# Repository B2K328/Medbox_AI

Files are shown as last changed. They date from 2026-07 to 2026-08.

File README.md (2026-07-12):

# 🩺 MedBox AI  
### *Un boîtier médical intelligent et autonome utilisant l’Edge AI*  

  
  


---

## 📌 Présentation

**MedBox AI** est un projet de fin d’année (Licence 2 Informatique) visant à concevoir un **boîtier médical autonome** capable de réaliser un **diagnostic local en temps réel** à partir de constantes physiologiques.  

Le système embarque un modèle de classification exécuté directement sur un **ESP32** via **TensorFlow Lite Micro (TFLM)**, sans dépendance au cloud.

---

## 🎯 Objectifs du projet

- Concevoir une chaîne complète de **mesure → traitement → inférence → affichage** sur microcontrôleur.
- Exploiter l’**Edge AI** pour un diagnostic ultra-rapide et local.
- Garantir une architecture compatible avec les contraintes mémoire/CPU d’un ESP32.
- Démontrer la faisabilité d’un système médical intelligent à faible coût matériel.

---

## 🧠 Architecture embarquée (ESP32)

L’environnement d’exécution est fortement contraint :

| Élément | Spécification |
|---|---|
| Microcontrôleur | ESP32 |
| CPU | Xtensa double-cœur @ 240 MHz |
| Flash | 4 Mo |
| SRAM | 320 Ko |
| Cadre IA | TensorFlow Lite Micro (TFLM) |
| Allocation Tensor Arena | **8 Ko** (SRAM) |

---

## 🧩 Composants matériels

| Composant | Rôle |
|---|---|
| ESP32 | Unité centrale de contrôle et d’inférence |
| MAX30102 | Mesure du rythme cardiaque (BPM) et de la SpO2 |
| MLX90614 (IR) | Mesure de la température corporelle sans contact |
| Lecteur NFC | Lecture de l’âge patient depuis badge NFC |
| Écran OLED | Affichage des constantes et du diagnostic |

---

## 🔄 Flux logique du système (Machine à États)

Le firmware suit une séquence déterministe en **6 étapes** :

1. **Initialisation**
   - Bus I2C
   - Écran OLED
   - Capteurs
   - Moteur TensorFlow Lite Micro

2. **Attente NFC**
   - Scrutation active d’un badge
   - Lecture de l’**âge patient**

3. **Acquisition biométrique**
   - **MAX30102** : BPM + SpO2  
   - **MLX90614** : Température corporelle

4. **Prétraitement / Normalisation**
   - Transformation Z-Score des 4 variables :  
     **Âge, BPM, SpO2, Température**
   - Paramètres issus du scaler d’entraînement : `scaler_medbox.pkl`

5. **Inférence TinyML locale**
   - Injection du vecteur normalisé dans le tenseur d’entrée
   - Exécution du modèle TFLM sur ESP32
   - Récupération de l’index de pathologie (classification OMS)

6. **Restitution**
   - Affichage instantané des constantes + diagnostic sur OLED
   - Réinitialisation du cycle

---

## 🧮 Normalisation mathématique (Z-Score)

Avant inférence, chaque variable \(x\) est normalisée par :

\[
x_{\text{scaled}} = \frac{x - \mu}{\sigma}
\]

où :
- \(\mu\) = moyenne issue du dataset d’entraînement  
- \(\sigma\) = écart-type issu du dataset d’entraînement  

Cette étape garantit la cohérence entre les données capteurs en production et le domaine statistique appris par le modèle.

---

## ⚡ Performances mesurées (tests réels)

| Indicateur | Résultat |
|---|---|
| Accuracy du modèle (Python) | **95,63 %** |
| Temps d’inférence ESP32 | **126 à 136 µs** |
| Utilisation Flash | **27 %** |
| Variables globales | **9 %** |
| Tensor Arena SRAM | **8 Ko** |

### 🧪 Cas clinique simulé validé
Pour un patient simulé en **tachycardie + hypoxie sévère** :  
- 125 BPM  
- 85 % SpO2  
- 39.5 °C  

➡️ Le modèle embarqué détecte immédiatement **l’ID Pathologie OMS : 17** en **126 µs**.

---

## 🔒 Sécurité & confidentialité des données médicales

> [!IMPORTANT]  
> **MedBox AI fonctionne en Edge AI local** : l’inférence est réalisée directement sur l’ESP32, sans cloud.

> [!NOTE]  
> Cette architecture réduit l’exposition des données sensibles (constantes vitales), limite les dépendances réseau et améliore la résilience du système.

> [!WARNING]  
> Ce prototype est un **dispositif académique** et ne remplace pas un diagnostic médical professionnel.  
> Toute utilisation clinique réelle nécessite validation réglementaire, protocoles médicaux et conformité légale.

---

## 📁 Structure de projet recommandée

```text
Medbox_AI/
├─ src/                 # Code embarqué ESP32 (machine à états, capteurs, inférence)
│  ├─ main.ino
│  ├─ sensors/
│  ├─ nfc/
│  ├─ display/
│  └─ inference/
├─ model/               # Artefacts IA (modèle TFLite, paramètres de scaling)
│  ├─ medbox_model.tflite
│  ├─ model_data.h
│  └─ scaler_medbox.pkl
├─ docs/                # Documentation technique, schémas, rapport
│  ├─ architecture.md
│  ├─ bench_results.md
│  └─ images/
├─ data/                # Jeux de données / exports de test (si applicable)
├─ scripts/             # Scripts d’entraînement / conversion (Python)
└─ README.md
```

---

## 🛠️ Dépendances logicielles

À installer dans l’IDE Arduino (ou PlatformIO selon votre workflow) :

- **TensorFlowLite_ESP32** (TensorFlow Lite Micro pour ESP32)
- **Adafruit MLX90614 Library**
- **Librairie MAX30102** compatible ESP32
- **Librairie NFC** correspondant au module utilisé
- **Librairie écran OLED** (ex. SSD1306 selon le matériel)

---

## 🚀 Guide de démarrage rapide

### 1) Préparer l’environnement
1. Installer **Arduino IDE** (ou PlatformIO).
2. Ajouter la carte **ESP32** via le Boards Manager.
3. Installer les bibliothèques listées ci-dessus.

### 2) Préparer le projet
1. Cloner le dépôt :
   ```bash
   git clone https://github.com/B2K328/Medbox_AI.git
   cd Medbox_AI
   ```
2. Vérifier la présence :
   - du modèle embarqué (`.tflite` ou `model_data.h`)
   - des constantes de normalisation (issues de `scaler_medbox.pkl`)

### 3) Compiler & téléverser
1. Ouvrir `src/main.ino`.
2. Sélectionner la carte ESP32 et le port série.
3. Compiler puis téléverser.
4. Ouvrir le moniteur série pour observer :
   - l’acquisition capteur
   - les valeurs normalisées
   - le résultat d’inférence

---

## 🧪 Validation fonctionnelle

Checklist de validation recommandée :

- [ ] Initialisation I2C / capteurs / écran réussie  
- [ ] Lecture NFC de l’âge valide  
- [ ] Acquisition BPM / SpO2 / Température cohérente  
- [ ] Normalisation Z-Score conforme aux constantes d’entraînement  
- [ ] Inférence < 200 µs stable  
- [ ] Affichage OLED correct (constantes + ID OMS)

---

## 📚 Périmètre académique

Ce projet illustre une démarche d’ingénierie embarquée complète :

- conception d’une **pipeline TinyML** de bout en bout,
- adaptation aux contraintes d’un **microcontrôleur basse ressource**,
- intégration **capteurs + IA + IHM embarquée**.

---

## 👨‍💻 Auteur

**B2K328**  
Projet de fin d’année — **Licence 2 Informatique**  
Repository : [github.com/B2K328/Medbox_AI](https://github.com/B2K328/Medbox_AI)

---

## 📄 Licence

À préciser selon votre choix (`MIT`, `Apache-2.0`, ou licence académique spécifique).

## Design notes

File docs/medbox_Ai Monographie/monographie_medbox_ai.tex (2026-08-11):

\documentclass[12pt,a4paper]{report}

% ===================== PACKAGES =====================
\usepackage[utf8]{inputenc}
\usepackage[T1]{fontenc}
\usepackage[french]{babel}
\usepackage{lmodern}
\usepackage{geometry}
\geometry{a4paper, left=2.5cm, right=2.5cm, top=2.5cm, bottom=2.5cm}
\usepackage{graphicx}
\usepackage{float}
\usepackage{amsmath, amssymb}
\usepackage{listings}
\usepackage{xcolor}
\usepackage{booktabs}
\usepackage{hyperref}
\hypersetup{
    colorlinks=true,
    linkcolor=black,
    citecolor=black,
    urlcolor=blue,
    pdftitle={Monographie - MedBox AI},
}
\usepackage{fancyhdr}
\usepackage{titlesec}
\usepackage{setspace}
\onehalfspacing

% ===================== CONFIG CODE (LISTINGS) =====================
\lstset{
    basicstyle=\ttfamily\small,
    breaklines=true,
    frame=single,
    backgroundcolor=\color{gray!10},
    numbers=left,
    numberstyle=\tiny,
    keywordstyle=\color{blue},
    commentstyle=\color{gray},
}

% ===================== EN-TETES =====================
\setlength{\headheight}{14pt}
\pagestyle{fancy}
\fancyhf{}
\fancyhead[L]{\leftmark}
\fancyfoot[C]{\thepage}
\renewcommand{\headrulewidth}{0.4pt}

% ===================== INFOS A COMPLETER =====================
\newcommand{\titreProjet}{MedBox AI}
\newcommand{\sousTitre}{Boîtier de diagnostic médical embarqué basé sur l'intelligence artificielle}
\newcommand{\nomEtudiant}{BIDIKI Enock}
\newcommand{\nomEtablissement}{Université Protestante au Congo}
\newcommand{\nomFaculte}{Faculté des Sciences Informatiques}
\newcommand{\nomFormation}{Licence 2 -- LMD}
\newcommand{\anneeUniv}{Année académique 2025 -- 2026}

\begin{document}

% ===================== PAGE DE TITRE =====================
\begin{titlepage}
    \centering
    {\scshape\Large \nomEtablissement \par}
    {\scshape \nomFaculte \par}
    {\scshape \nomFormation \par}
    \vspace{2cm}

    {\huge\bfseries Monographie \par}
    \vspace{1cm}
    \rule{\linewidth}{0.5mm} \\[0.4cm]
    {\Huge \titreProjet \par}
    {\large \sousTitre \par}
    \rule{\linewidth}{0.5mm} \\[1.5cm]

    \begin{minipage}{0.45\textwidth}
        \begin{center} \large
            \textit{Réalisé par :}\\
            \nomEtudiant
        \end{center}
    \end{minipage}

    \vfill
    {\large \anneeUniv \par}
\end{titlepage}

% ===================== RESUME =====================
\chapter*{Résumé}
\addcontentsline{toc}{chapter}{Résumé}

Ce projet de monographie s'inscrit dans le cadre de l'initiation à la démarche scientifique et à l'ingénierie embarquée au sein de la Faculté des Sciences Informatiques. Il porte sur la conception d'un système médical embarqué complet, nommé MedBox AI, capable de mesurer automatiquement plusieurs constantes vitales d'un patient et de proposer localement un diagnostic parmi dix-neuf profils physiologiques et pathologiques, à l'aide d'un modèle d'intelligence artificielle embarqué sur un microcontrôleur. L'approche suivie combine la constitution d'un jeu de données médicales, l'entraînement d'un réseau de neurones de classification, la conversion de ce modèle pour une exécution locale sur microcontrôleur, la conception d'un système électronique intégrant plusieurs capteurs biométriques et un module d'identification par carte à puce sans contact, ainsi que le développement d'une chaîne logicielle complémentaire assurant la remontée opportuniste des résultats vers une plateforme web de suivi. Les résultats obtenus démontrent la faisabilité d'un diagnostic médical préliminaire entièrement autonome et sans connexion réseau, complété par un historique consultable, tout en révélant plusieurs limites techniques inhérentes à un prototype construit avec des composants grand public. Ce travail illustre ainsi la capacité de l'étudiant à mobiliser des compétences pluridisciplinaires, allant de l'intelligence artificielle à l'électronique embarquée en passant par le développement web, pour concevoir un système fonctionnel répondant à une problématique concrète.

% ===================== SOMMAIRE =====================
\tableofcontents
\clearpage

% ===================== CHAPITRE 1 : INTRODUCTION GENERALE =====================
\chapter{Introduction générale}

\section{Contexte}
L'accès à un premier diagnostic médical fiable et rapide reste un enjeu majeur, en particulier dans les contextes où le personnel soignant est peu disponible ou éloigné (zones rurales, postes de secours, dépistage de masse). Les objets connectés couplés à l'intelligence artificielle embarquée, communément désignée par le terme \textit{TinyML}, offrent aujourd'hui une réponse crédible à cette problématique : ils permettent de réaliser une analyse médicale préliminaire directement sur un microcontrôleur, sans connexion internet ni serveur distant. C'est dans cette optique que s'inscrit le projet MedBox AI, un boîtier autonome construit autour d'un microcontrôleur ESP32, capable de mesurer plusieurs constantes vitales d'un patient et d'exécuter localement un modèle d'intelligence artificielle pour proposer un diagnostic.

\section{Problématique}
La problématique centrale du projet peut être formulée ainsi : comment concevoir un système embarqué, autonome et peu coûteux, capable de mesurer automatiquement les constantes vitales d'un patient et d'en déduire, localement et en temps réel, un diagnostic parmi un ensemble de profils physiologiques et pathologiques courants, tout en restant réalisable avec des composants électroniques grand public et des bibliothèques logicielles ouvertes ?

\subsection*{Sous-questions techniques}
\begin{itemize}
    \item Quelles grandeurs physiologiques mesurer, et avec quels capteurs, pour obtenir une donnée exploitable par un modèle d'intelligence artificielle ?
    \item Comment entraîner un modèle de classification suffisamment précis tout en restant assez léger pour tenir dans la mémoire limitée d'un microcontrôleur ?
    \item Comment garantir la fiabilité des mesures issues de capteurs bas coût, sujettes au bruit et aux artefacts de mouvement ?
    \item Comment organiser le déroulement logiciel (acquisition, traitement, inférence, affichage) de manière robuste, malgré les contraintes matérielles du microcontrôleur ?
\end{itemize}

\section{Objectifs}

\subsection{Objectif général}
Concevoir et réaliser un prototype de boîtier médical embarqué, autonome et fonctionnel, capable de mesurer les constantes vitales d'un patient et de fournir localement un diagnostic à l'aide d'un modèle d'intelligence artificielle, en mobilisant les compétences acquises en programmation, en électronique embarquée et en apprentissage automatique.

\subsection{Objectifs spécifiques}
\begin{itemize}
    \item Concevoir un boîtier matériel intégrant les capteurs nécessaires à la mesure de quatre grandeurs : âge, fréquence cardiaque, saturation en oxygène et température corporelle.
    \item Constituer un jeu de données représentatif de dix-neuf profils physiologiques et pathologiques, puis entraîner un modèle de classification multiclasse.
    \item Convertir ce modèle au format TensorFlow Lite et l'embarquer sur le microcontrôleur pour une inférence entièrement locale.
    \item Développer une machine à états gérant l'identification du patient, l'acquisition des capteurs, l'inférence de l'intelligence artificielle et l'affichage du résultat.
    \item Identifier, documenter et corriger les dysfonctionnements rencontrés lors de l'intégration matérielle et logicielle.
    \item Évaluer les performances et les limites du système à travers des tests, tant en simulation qu'avec le matériel réel.
\end{itemize}

\section{Méthodologie adoptée}
Le travail s'est déroulé en plusieurs étapes successives. L'étudiant a d'abord mené une analyse du besoin et une recherche des composants électroniques adaptés. Il a ensuite procédé à la constitution d'un jeu de données et à l'entraînement d'un modèle d'intelligence artificielle sous Python, avant de convertir ce modèle pour une exécution embarquée. La phase suivante a consisté en l'implémentation pratique du firmware sur microcontrôleur ESP32, organisée en modules logiciels indépendants (capteurs, identification, intelligence artificielle, affichage). Des tests répétés, en simulation puis avec les capteurs physiques, ont permis de détecter et corriger plusieurs dysfonctionnements. Tout au long du processus, l'étudiant a été encadré par un enseignant référent.

\section{Structure du document}
Ce document est structuré en cinq chapitres principaux. Le premier chapitre, \textit{Introduction générale}, présente le contexte, la problématique, les objectifs, la méthodologie et l'organisation du travail. Le deuxième chapitre, \textit{Cadre théorique et technologique}, définit les concepts clés mobilisés et décrit les outils et technologies utilisés. Le troisième chapitre, \textit{Réalisation du projet}, présente les étapes concrètes du développement de la solution. Le quatrième chapitre, \textit{Difficultés rencontrées et limites}, expose les contraintes techniques rencontrées et les limites observées du prototype. Enfin, le cinquième chapitre, \textit{Conclusion générale}, récapitule le travail effectué, présente les apports du projet et propose des perspectives d'amélioration.

% ===================== CHAPITRE 2 : CADRE THEORIQUE ET TECHNOLOGIQUE =====================
\chapter{Cadre théorique et technologique}

\section{Définitions des concepts clés}

\textbf{Intelligence artificielle embarquée (TinyML).} Sous-domaine de l'apprentissage automatique consistant à déployer des modèles d'intelligence artificielle directement sur des microcontrôleurs à ressources très limitées (quelques kilo-octets à quelques mégaoctets de mémoire), sans dépendre d'un serveur distant. Cette approche est au cœur de MedBox AI, dont le modèle de diagnostic s'exécute entièrement sur l'ESP32.

\textbf{Réseau de neurones de type Perceptron Multicouche (MLP).} Modèle d'apprentissage automatique composé de plusieurs couches de neurones artificiels interconnectées, capable d'apprendre à classer des données à partir d'exemples. Dans ce projet, un MLP est utilisé pour classer les mesures d'un patient parmi dix-neuf profils physiologiques et pathologiques.

\textbf{Normalisation Z-score.} Technique de mise à l'échelle des données consistant à soustraire la moyenne et diviser par l'écart-type de chaque variable, afin que toutes les variables d'entrée du modèle aient une échelle comparable. Cette étape est indispensable pour la stabilité de l'apprentissage d'un réseau de neurones.

\textbf{Quantification de modèle.} Processus de compression d'un modèle d'intelligence artificielle consistant à réduire la précision numérique de ses paramètres, afin de diminuer sa taille en mémoire et d'accélérer son exécution sur un matériel aux ressources limitées.

\textbf{Communication I2C.} Protocole de communication série permettant à plusieurs composants électroniques (capteurs, écran, module de communication) de dialoguer avec un microcontrôleur sur un même bus, en utilisant seulement deux fils.

\textbf{Photopléthysmographie.} Technique de mesure optique consistant à éclairer la peau (généralement le doigt) avec une lumière infrarouge et rouge, puis à analyser la lumière réfléchie pour en déduire la fréquence cardiaque et la saturation en oxygène du sang.

\textbf{Communication en champ proche (NFC).} Technologie de communication sans fil à très courte portée, utilisée dans ce projet pour lire l'âge d'un patient stocké sur un badge, via un module dédié.

\textbf{Communication série.} Mode de transmission de données caractère par caractère sur une liaison filaire (ici, le câble USB reliant le microcontrôleur à un ordinateur), utilisé dans ce projet pour faire remonter les résultats de diagnostic vers une base de données, sans recourir à une connexion réseau.

\textbf{Architecture client-serveur et pages dynamiques (PHP).} Modèle dans lequel un serveur génère du contenu (ici des pages web) à la demande, en interrogeant une base de données, avant de l'envoyer au navigateur du client. Contrairement à une page statique, une page dynamique affiche toujours des données à jour.

\textbf{Opérations CRUD.} Acronyme désignant les quatre opérations fondamentales de manipulation de données dans une application : création (\textit{Create}), lecture (\textit{Read}), mise à jour (\textit{Update}) et suppression (\textit{Delete}). Ce modèle structure la conception de la plateforme web du projet.

\textbf{JSON (\textit{JavaScript Object Notation}).} Format de données textuel léger, utilisé pour transmettre des informations structurées entre un serveur (PHP) et un script exécuté dans le navigateur (JavaScript).

\section{Présentation des outils ou technologies utilisés}

\begin{itemize}
    \item \textbf{ESP32} : microcontrôleur central du projet, choisi pour sa puissance de calcul suffisante, son faible coût et sa capacité à exécuter des modèles d'intelligence artificielle allégés. Il pilote l'ensemble des périphériques et exécute le firmware complet.
    \item \textbf{MAX30102} (bibliothèque SparkFun) : capteur optique de photopléthysmographie permettant de mesurer la fréquence cardiaque et la saturation en oxygène. Choisi pour son faible coût et sa large documentation communautaire.
    \item \textbf{MLX90614} (bibliothèque Adafruit) : capteur infrarouge sans contact permettant de mesurer la température corporelle du patient sans contact direct, pour des raisons d'hygiène.
    \item \textbf{PN532} (bibliothèque Adafruit) : module de lecture NFC utilisé pour identifier le patient et extraire son âge depuis un badge.
    \item \textbf{Écran OLED SSD1306} : afficheur utilisé pour présenter les mesures en temps réel puis le diagnostic final à l'utilisateur.
    \item \textbf{Python, avec les bibliothèques pandas, scikit-learn et TensorFlow/Keras} : environnement utilisé pour préparer le jeu de données, entraîner le modèle de classification et le convertir au format embarqué.
    \item \textbf{TensorFlow Lite for Microcontrollers} (via les bibliothèques \texttt{tflm\_esp32} et \texttt{eloquent\_tinyml}) : cadriciel permettant d'exécuter le modèle d'intelligence artificielle quantifié directement sur l'ESP32.
    \item \textbf{Arduino IDE / C++} : environnement de développement utilisé pour écrire, compiler et téléverser le firmware embarqué sur l'ESP32.
    \item \textbf{Microsoft Excel} : utilisé pour la constitution et l'organisation du jeu de données de 9500 échantillons ayant servi à l'entraînement du modèle.
    \item \textbf{Python (bibliothèques pyserial et pymysql)} : utilisé pour développer le programme relais (« pont ») assurant la lecture du port série de l'ESP32 et l'enregistrement des mesures dans la base de données.
    \item \textbf{MySQL} : système de gestion de base de données relationnelle utilisé pour stocker de manière persistante les patients et leurs mesures successives.
    \item \textbf{PHP} : langage de programmation côté serveur utilisé pour développer les quatre pages de la plateforme web (tableau de bord, fiche patient, liste des patients, file de finalisation), en générant du HTML à jour à chaque consultation.
    \item \textbf{Chart.js (bibliothèque JavaScript, hébergée localement)} : utilisée pour dessiner les courbes d'évolution des constantes vitales d'un patient dans son historique, sans nécessiter de connexion internet.
    \item \textbf{HTML/CSS} : utilisés pour la structure et la mise en forme visuelle de la plateforme web, avec une direction graphique inspirée des interfaces de dispositifs médicaux.
\end{itemize}

% ===================== CHAPITRE 3 : REALISATION DU PROJET =====================
\chapter{Réalisation du projet}

\section{Analyse des besoins}
Le système devait répondre aux besoins fonctionnels suivants :
\begin{itemize}
    \item Identifier un patient de manière simple et rapide, sans saisie manuelle.
    \item Mesurer automatiquement, sans intervention d'un professionnel de santé, quatre grandeurs physiologiques : âge, fréquence cardiaque, saturation en oxygène et température corporelle.
    \item Traiter ces données localement pour produire un diagnostic parmi dix-neuf profils possibles, sans dépendre d'une connexion internet.
    \item Afficher un résultat clair et lisible à l'utilisateur.
    \item Conserver un historique des mesures de chaque patient, consultable ultérieurement, afin de permettre un suivi dans le temps plutôt qu'une simple mesure ponctuelle.
\end{itemize}

Ces besoins fonctionnels s'accompagnaient de contraintes non fonctionnelles fortes, propres à l'embarqué : mémoire vive très limitée (quelques centaines de kilo-octets), nécessité d'un fonctionnement autonome (sans serveur), et budget matériel restreint imposant l'usage de capteurs grand public plutôt que de dispositifs médicaux certifiés.

\section{Architecture de la solution}
Le système MedBox AI repose sur une architecture globale en trois niveaux : le dispositif embarqué, qui réalise le diagnostic de manière autonome ; un programme relais, qui fait remonter les mesures vers une base de données lorsque les conditions le permettent ; et une plateforme web, qui permet de consulter l'historique des patients. Cette organisation garantit qu'aucun de ces trois niveaux n'est indispensable au fonctionnement des autres : le diagnostic reste possible même sans remontée de données, et la remontée reste possible même sans consultation web immédiate.

\begin{figure}[H]
    \centering
    % \includegraphics[width=0.7\textwidth]{schema_architecture.png}
    \caption{Schéma de l'architecture globale de MedBox AI (dispositif, pont série, base de données, plateforme web)}
    \label{fig:architecture}
\end{figure}

\subsection*{Le dispositif embarqué}
Le boîtier MedBox AI repose sur un microcontrôleur ESP32 connecté en bus I2C à l'ensemble des périphériques. L'architecture logicielle est organisée en modules indépendants, chacun responsable d'un sous-système :

\begin{itemize}
    \item \texttt{config.h} : définition des états de la machine, de la structure de données patient, des constantes de normalisation et de calibration.
    \item \texttt{nfc\_module.h} : gestion de l'identification du patient via le module PN532.
    \item \texttt{sensors\_module.h} : gestion de l'acquisition des mesures physiologiques (MAX30102, MLX90614).
    \item \texttt{ia\_inference.h} : normalisation des données et exécution de l'inférence TensorFlow Lite Micro.
    \item \texttt{display\_module.h} : gestion de l'affichage sur l'écran OLED.
\end{itemize}

Le fonctionnement global est piloté par une \textbf{machine à états finis}, qui structure le cycle de vie complet d'une mesure patient :

\begin{enumerate}
    \item \texttt{STATE\_WAIT\_NFC} : attente du scan d'un badge NFC, permettant d'extraire l'âge du patient.
    \item \texttt{STATE\_READ\_SENSORS} : acquisition de la température (détection de présence), puis de la fréquence cardiaque et de la saturation en oxygène.
    \item \texttt{STATE\_SCALING} : normalisation Z-score des quatre variables mesurées.
    \item \texttt{STATE\_INFERENCE} : exécution de l'inférence TinyML locale.
    \item \texttt{STATE\_SHOW\_RESULT} : affichage du diagnostic pendant dix secondes, avant réinitialisation pour un nouveau patient.
\end{enumerate}

\subsection*{La remontée des données par liaison série}
Le dispositif ne communique jamais directement avec la base de données. La remontée des mesures s'effectue par liaison série (le câble USB reliant déjà le dispositif à un ordinateur), plutôt que par le réseau WiFi, pour rester cohérente avec l'objectif d'autonomie hors ligne du dispositif : aucune configuration réseau n'est nécessaire, et les données transmises restent lisibles directement pour faciliter le débogage.

Un programme relais, appelé « pont » et écrit en Python, écoute en continu le port série. À chaque mesure, le dispositif imprime une ligne de texte au format suivant, les champs étant séparés par des points-virgules et préfixés par le mot-clé \texttt{MEDBOX;} :
\begin{center}
\texttt{MEDBOX;uid;age;bpm;spo2;temperature;confiance;classe}
\end{center}

Ce préfixe permet au pont de distinguer les lignes de mesure des nombreux autres messages que le dispositif imprime par ailleurs (démarrage, étapes de mesure) : seules les lignes commençant exactement par \texttt{MEDBOX;} sont traitées, les autres étant ignorées.

Cette remontée est qualifiée d'\textbf{opportuniste} : elle n'a lieu que si un câble est branché et qu'un pont est actif à l'écoute, mais le diagnostic réalisé par le dispositif n'en dépend jamais. La base de données ne joue ainsi qu'un rôle de mémoire optionnelle, jamais celui d'un maillon indispensable au fonctionnement médical du système.

\subsection*{La plateforme web de suivi}
Une plateforme web, développée en PHP et connectée à une base de données MySQL, permet de consulter l'historique des mesures. Elle se compose de quatre pages couvrant les opérations CRUD (création, lecture, mise à jour, suppression) : un tableau de bord (statistiques et dernières mesures), une fiche patient (historique et courbes d'évolution), une liste des patients (avec suppression), et une file de finalisation (complétion des patients créés automatiquement à partir d'un badge inconnu). La création d'un patient n'est pas assurée par une page web, mais déclenchée automatiquement dès la réception d'une mesure associée à un badge inconnu.

Les courbes d'évolution des constantes vitales sont dessinées avec la bibliothèque JavaScript Chart.js, hébergée localement sur le serveur pour un fonctionnement hors ligne. Les données, lues en base par PHP, sont transmises au script JavaScript via la fonction \texttt{json\_encode}, qui convertit un tableau PHP en un format directement exploitable par Chart.js. Un contrôle affiche les courbes uniquement à partir de deux mesures disponibles, une mesure isolée ne pouvant traduire aucune tendance.

Le style visuel de la plateforme s'inspire des interfaces de dispositifs médicaux (fond clair, palette bleu profond et sarcelle, cartes à coins arrondis), avec un codage couleur à quatre niveaux (normal, alerte, sévère, critique) permettant de repérer une situation grave en un coup d'œil — une information que l'écran OLED du dispositif, plus contraint, ne pouvait pas transmettre.

\section{Étapes de mise en œuvre}

\subsection*{Phase de conception}
Le projet a débuté par la définition des dix-neuf profils physiologiques et pathologiques à reconnaître (états normaux selon l'âge, variations physiologiques légères, et pathologies de sévérité croissante telles que tachycardie, bradycardie, hypoxie, fièvre ou choc). Les seuils retenus pour chaque classe (plages de fréquence cardiaque, de saturation en oxygène et de température selon l'âge) ont été construits à partir de tables de référence clinique reconnues, notamment le Manuel MSD, les directives \textit{Pediatric Advanced Life Support} de l'American Heart Association pour les seuils pédiatriques, ainsi que les repères cliniques de détresse et de choc publiés par l'Organisation mondiale de la santé.

Un jeu de données synthétique de 9500 échantillons a ensuite été constitué, parfaitement équilibré entre les dix-neuf classes (500 échantillons par classe), avec pour chaque échantillon quatre variables d'entrée (âge, fréquence cardiaque, saturation en oxygène, température) et une étiquette de classe. Le recours à des données synthétiques plutôt qu'à des données patients réelles se justifie à la fois sur le plan éthique et sur le plan pratique : les principes relatifs aux données de l'Organisation mondiale de la santé rappellent qu'aucune donnée réelle de patient ne doit être utilisée sans infrastructure de protection et d'anonymisation adaptée, hors de portée d'un projet étudiant. Sur le plan scientifique, la littérature reconnaît par ailleurs l'usage de données synthétiques comme une pratique validée en santé numérique, en particulier pour l'éducation, la formation et le développement de logiciels de santé, ainsi que pour tester des algorithmes et générer des hypothèses avant toute manipulation de données réelles.

\subsection*{Phase d'implémentation}

\paragraph{Entraînement du modèle d'intelligence artificielle.} Un réseau de neurones de type Perceptron Multicouche a été entraîné sous Python/Keras, avec l'architecture suivante : une couche d'entrée à 4 neurones, une première couche cachée de 32 neurones (activation ReLU), une couche de régularisation (Dropout à 10~\%), une seconde couche cachée de 16 neurones (activation ReLU), et une couche de sortie de 19 neurones (activation Softmax). L'entraînement a été réalisé avec l'optimiseur Adam, une fonction de perte de type \textit{categorical crossentropy}, sur 50 itérations complètes (\textit{epochs}) et des lots de 32 échantillons, sur un ensemble d'entraînement représentant 80~\% du jeu de données (les 20~\% restants formant l'ensemble de test).

\paragraph{Conversion pour l'embarqué.} Le modèle entraîné a ensuite été converti au format TensorFlow Lite avec quantification par défaut, afin de réduire sa taille et d'accélérer son exécution sur microcontrôleur. Le fichier obtenu a été transformé en tableau d'octets C++, directement intégrable dans le firmware. Sur l'ESP32, l'inférence est exécutée avec une zone mémoire de seulement 8~kilo-octets de SRAM, illustrant la légèreté du modèle final.

\paragraph{Développement du firmware embarqué.} Le firmware a été développé en C++ sous Arduino IDE, avec la structure modulaire décrite en section 3.2. Un mode de simulation a été ajouté à deux niveaux du système : un mode de simulation NFC (badge simulé par une valeur d'âge fixe dans le code) et un mode de saisie manuelle des constantes vitales via le moniteur série, permettant de tester les dix-neuf classes de sortie du modèle sans avoir à reproduire physiquement chaque état pathologique avec les capteurs.

\paragraph{Développement du pont série et de la base de données.} Un programme relais Python, exploitant les bibliothèques \texttt{pyserial} et \texttt{pymysql}, a été développé pour écouter le port série, filtrer les lignes de mesure valides et les enregistrer dans une base de données MySQL. Une logique d'enrôlement automatique des patients a été implémentée : un badge inconnu déclenche la création d'un nouveau patient au statut « en attente de finalisation », complété ultérieurement via la plateforme web.

\paragraph{Développement de la plateforme web.} Les quatre pages de la plateforme (tableau de bord, fiche patient, liste des patients, file de finalisation) ont été développées en PHP, avec une interrogation directe de la base MySQL à chaque consultation. L'intégration de la bibliothèque Chart.js, associée à la fonction PHP \texttt{json\_encode} pour transmettre les données au script JavaScript, a permis d'afficher les courbes d'évolution des constantes vitales de chaque patient.

\subsection*{Phase de tests}
Les tests ont été menés à deux niveaux. D'une part, le modèle a été évalué automatiquement sur l'ensemble de test Python (1900 échantillons non vus pendant l'entraînement). D'autre part, le prototype matériel complet a été testé de manière itérative, ce qui a permis de mettre en évidence plusieurs dysfonctionnements (détaillés au chapitre 4) et d'orienter les corrections successives apportées au firmware, notamment sur la fiabilité de la mesure cardiaque et sur la lecture des badges NFC.

\section{Résultats obtenus}

\subsection*{Performance du modèle d'intelligence artificielle}
Après entraînement, le modèle atteint une précision de \textbf{95,58~\%} sur l'ensemble de test. Cette précision est quasiment intégralement préservée après conversion et quantification au format TensorFlow Lite, confirmant que la compression du modèle n'a pas dégradé significativement ses performances.

\begin{figure}[H]
    \centering
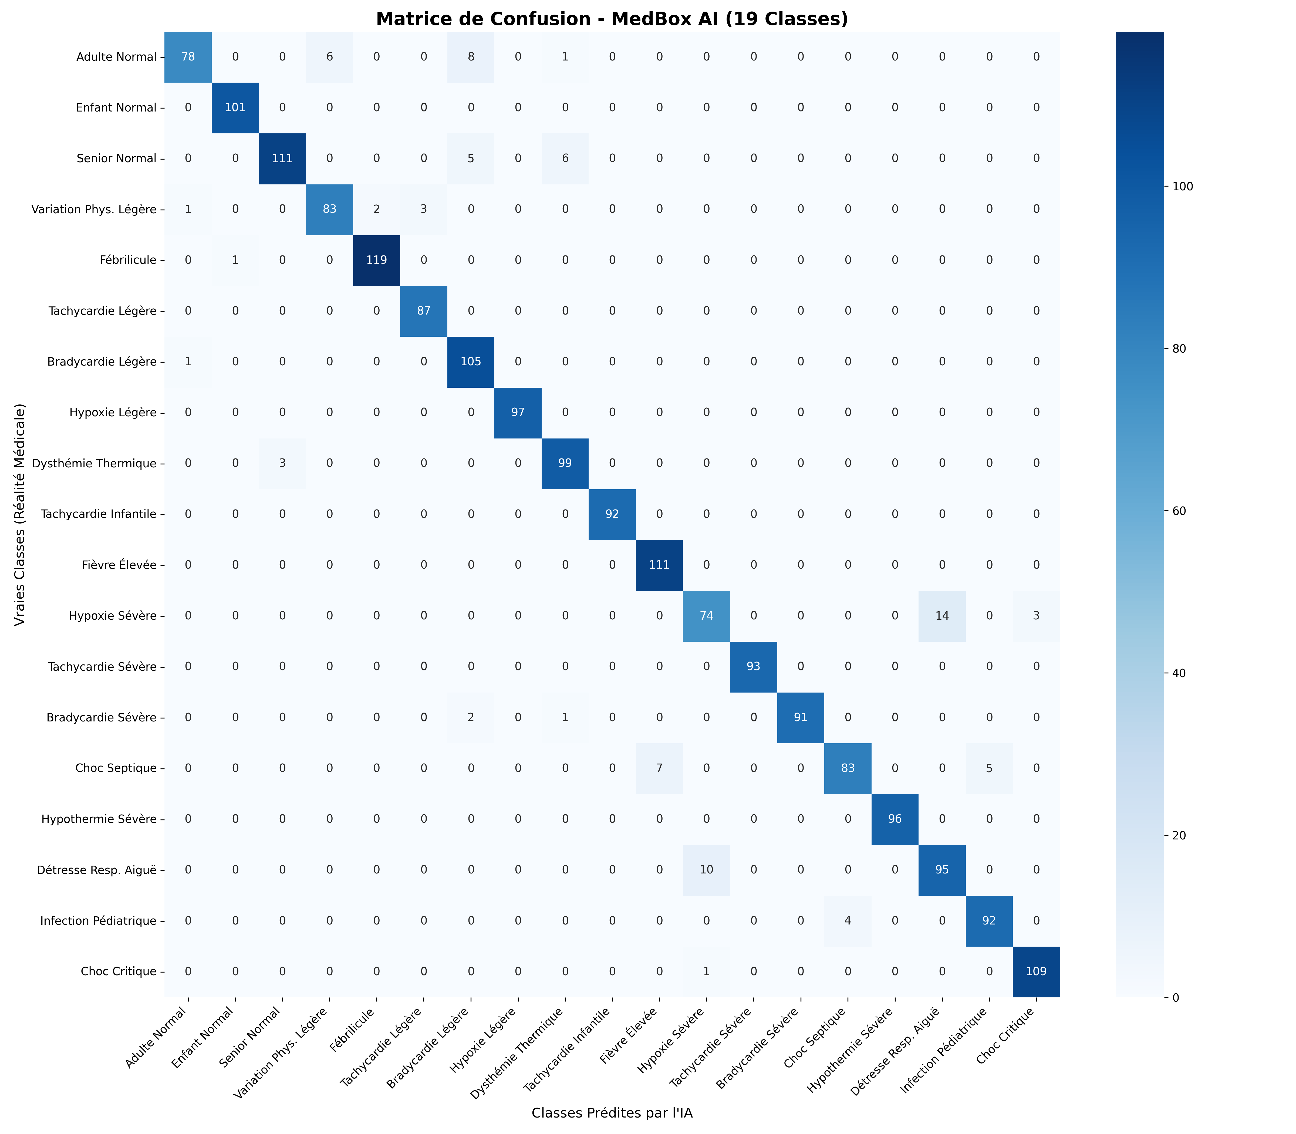
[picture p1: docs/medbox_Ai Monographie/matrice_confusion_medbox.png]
    
    \caption{Matrice de confusion du modèle MedBox AI sur les 19 classes}
    \label{fig:confusion}
\end{figure}

L'analyse de la matrice de confusion (figure~\ref{fig:confusion}) montre que la quasi-totalité des classes sont très bien reconnues. Les rares confusions observées concernent presque exclusivement des classes physiologiquement proches, par exemple \textit{Adulte Normal} confondu occasionnellement avec \textit{Variation Physiologique Légère} ou \textit{Tachycardie Légère}, ou encore \textit{Hypoxie Sévère} confondue avec \textit{Infection Pédiatrique Grave} — des états graves partageant des profils de constantes vitales proches. Ces confusions restent limitées et concentrées sur des cas cliniquement voisins, ce qui confirme la pertinence du modèle pour un usage de premier tri, tout en soulignant qu'il ne saurait remplacer un diagnostic médical complet.

\subsection*{Résultats du prototype matériel}
Une fois le firmware corrigé (voir chapitre 4), le boîtier fonctionne de bout en bout : lecture d'un badge NFC, mesure de la température par calibration empirique, mesure de la fréquence cardiaque et de la saturation en oxygène par cycles successifs, puis inférence et affichage du diagnostic. La calibration du capteur de température, réalisée à partir de huit mesures comparatives avec un thermomètre de référence, a permis de déterminer un offset moyen de correction de +3,98~°C (écart-type des écarts individuels de 0,83~°C), rendant les températures transmises au modèle cohérentes avec la température corporelle réelle. Concernant la mesure cardiaque, des essais répétés sur un même sujet au repos ont révélé une variabilité significative des valeurs retenues (de 83 à 166 battements par minute selon les essais), reflétant les limites du capteur bas coût utilisé plutôt qu'un défaut de la chaîne logicielle de traitement.

\subsection*{Résultats de la remontée de données et de la plateforme web}
La chaîne complète de remontée des données a été validée : chaque diagnostic produit par le dispositif est imprimé sur le port série au format attendu, capté par le pont Python, puis enregistré dans la base MySQL avec application correcte de la logique d'enrôlement (rattachement à un patient existant ou création automatique d'un nouveau patient pour un badge inconnu). La plateforme web permet de consulter cet historique : le tableau de bord affiche les dernières mesures, la fiche patient présente les courbes d'évolution des constantes vitales dès que deux mesures ou plus sont disponibles, et le codage couleur à quatre niveaux de gravité permet une lecture rapide de la situation d'un patient. Le caractère opportuniste de cette remontée a également été vérifié : le dispositif continue de produire des diagnostics normalement lorsque le pont n'est pas actif, confirmant que la base de données reste une fonctionnalité complémentaire et non une dépendance du système de diagnostic.

% ===================== CHAPITRE 4 : DIFFICULTES ET LIMITES =====================
\chapter{Difficultés rencontrées et limites}

\section{Difficultés rencontrées}
Plusieurs dysfonctionnements techniques ont été identifiés et corrigés au cours du développement du prototype. Ce chapitre les documente de manière transparente, dans un souci d'honnêteté scientifique.

\paragraph{Authentification manquante en lecture NFC.} La fonction de lecture des badges Mifare Classic appelait la lecture d'un bloc mémoire sans authentification préalable du secteur, alors qu'une carte Mifare Classic exige cette authentification avant toute lecture. La lecture échouait donc silencieusement et le système retombait systématiquement sur une valeur d'âge de secours. Correction apportée : ajout de l'authentification par clé par défaut avant chaque lecture du bloc concerné.

\paragraph{Incohérence de format entre écriture et lecture NFC.} Le script d'écriture initial stockait l'âge en texte, alors que la logique de lecture interprétait le premier octet comme une valeur numérique brute, produisant des âges erronés en sortie. Correction apportée : alignement du format d'écriture sur le format brut attendu en lecture.

\paragraph{Calibration insuffisante du capteur de température.} Le capteur infrarouge sans contact mesure la température de peau, systématiquement inférieure de plusieurs degrés à la température corporelle centrale. Sans correction, l'entrée transmise à l'intelligence artificielle restait proche de 32-33~°C, provoquant une classification systématique en « hypothermie sévère ». Correction apportée : calibration empirique à partir de huit mesures comparatives, avec un offset moyen de +3,98~°C appliqué uniquement à la valeur transmise à l'IA et à l'affichage.

\paragraph{Absence de retour visuel après le scan du badge.} Après un scan réussi, l'écran restait figé sur l'écran d'attente jusqu'à la fin complète de la mesure des capteurs. Correction apportée : ajout d'un écran de confirmation intermédiaire (âge lu et signal sonore).

\paragraph{Crash mémoire lors de l'agrandissement de la fenêtre de capture cardiaque.} Une tentative d'agrandir la fenêtre de capture du capteur cardiaque (de 100 à 400 échantillons), pour tenter de stabiliser le calcul du rythme cardiaque, a provoqué un incident critique (\textit{Guru Meditation Error}). La cause identifiée est que la bibliothèque de calcul utilisée repose sur des tableaux de travail internes de taille fixe, codée en dur à 100 échantillons, indépendamment du paramètre transmis. Dépasser cette limite provoque une écriture hors des zones mémoire allouées. Correction apportée : retour à une fenêtre de 100 échantillons (contrainte non modifiable sans réécrire la bibliothèque), compensée par la multiplication du nombre de cycles de mesure indépendants (passé de 1 à 5).

\paragraph{Contention du bus I2C pendant la capture cardiaque.} L'écran OLED et le capteur cardiaque partageant le même bus I2C, le rafraîchissement de l'écran pendant la capture bloquait le bus 20 à 30 millisecondes à chaque appel, perturbant la régularité temporelle du signal nécessaire au calcul fiable du rythme cardiaque. Correction apportée : suppression des mises à jour d'écran pendant la capture, l'affichage n'étant désormais rafraîchi qu'une seule fois au début de chaque cycle de mesure.

\paragraph{Instabilité persistante des mesures cardiaques.} Malgré les corrections précédentes, des valeurs physiologiquement improbables ont continué à apparaître ponctuellement, en particulier lors de micro-mouvements du doigt. Plusieurs corrections cumulatives ont été apportées : renforcement du lissage matériel, multiplication des cycles de mesure indépendants, filtrage des valeurs hors plage physiologique plausible (fréquence cardiaque entre 40 et 200 battements par minute, saturation entre 70 et 100~\%), calcul de la médiane des cycles valides plutôt qu'une moyenne, et ajout d'un garde-fou détectant les cas de doublement de fréquence (phénomène harmonique connu de l'algorithme de calcul), avec préférence donnée à la fréquence fondamentale la plus basse.

\paragraph{Séparation du firmware d'écriture des badges.} L'écriture et la lecture des badges NFC ne pouvant cohabiter dans un même programme exécuté par le microcontrôleur, un programme indépendant a dû être développé spécifiquement pour la préparation des badges, nécessitant un changement de programme téléversé à chaque modification de badge.

\section{Limites de la solution}

\begin{itemize}
    \item \textbf{Précision de la mesure de température.} L'offset de calibration repose sur seulement huit mesures comparatives réalisées sur un nombre restreint de sujets. La marge d'erreur réaliste à attendre en usage reste supérieure à celle d'un thermomètre médical certifié ; cette calibration est indicative et n'a pas été validée cliniquement.
    \item \textbf{Fiabilité du capteur cardiaque.} Même après filtrage, cycles multiples et calcul par médiane, des écarts de mesure significatifs ont été observés sur une même personne au repos. Cette variabilité reflète une limite réelle du capteur bas coût utilisé et de l'algorithme de démonstration associé, qui n'intègrent pas les techniques de rejet de mouvement des oxymètres de pouls commerciaux certifiés.
    \item \textbf{Absence de validation clinique.} Ni les capteurs, ni le modèle de classification, ni les seuils de décision utilisés n'ont été validés par du personnel médical qualifié ni comparés à des dispositifs certifiés. MedBox AI reste un prototype éducatif et ne doit en aucun cas être utilisé comme outil de diagnostic réel.
    \item \textbf{Dépendance au mode de simulation.} Le paramètre de simulation NFC doit être explicitement désactivé pour un usage avec de véritables badges. Un oubli à ce niveau fausserait silencieusement les résultats, sans message d'erreur explicite à l'utilisateur.
    \item \textbf{Couverture de test incomplète du modèle.} La validation des dix-neuf classes de sortie repose majoritairement sur le mode de saisie manuelle des constantes vitales, faute de pouvoir reproduire physiquement chaque état critique avec les capteurs disponibles. La performance du modèle sur des données de capteurs réelles pour ces classes critiques reste donc partiellement non vérifiée.
    \item \textbf{Contrainte matérielle non résolue.} La fenêtre de capture du signal cardiaque, imposée par la bibliothèque de calcul utilisée, n'a pas pu être allongée sans provoquer un crash mémoire. Une fenêtre plus longue améliorerait probablement la stabilité du calcul, mais nécessiterait de réécrire l'algorithme de traitement du signal, ce qui n'a pas été réalisé dans le cadre de ce projet.
\end{itemize}

% ===================== CHAPITRE 5 : CONCLUSION GENERALE =====================
\chapter{Conclusion générale}

\section{Récapitulatif}
Ce projet a porté sur la conception d'un système médical embarqué complet, MedBox AI, combinant capteurs biométriques, identification par badge NFC, intelligence artificielle embarquée, remontée de données par liaison série et plateforme web de suivi. La démarche suivie a consisté à constituer un jeu de données de 9500 échantillons répartis en dix-neuf profils physiologiques et pathologiques, à entraîner un modèle de classification atteignant 95,58~\% de précision, puis à convertir et intégrer ce modèle sur un microcontrôleur ESP32 via TensorFlow Lite Micro. Le firmware embarqué, organisé autour d'une machine à états, a été développé, testé et corrigé de manière itérative pour aboutir à un prototype fonctionnel. Ce dispositif a ensuite été complété par un programme relais assurant l'enregistrement opportuniste des mesures dans une base de données, ainsi que par une plateforme web permettant de consulter l'historique et l'évolution de chaque patient.

\section{Apports du projet}
Ce travail a permis à l'étudiant de mobiliser et de développer des compétences pluridisciplinaires : préparation et exploitation d'un jeu de données, entraînement et évaluation d'un modèle d'apprentissage automatique, conversion de modèles pour l'embarqué, programmation en C++ sur microcontrôleur, intégration de capteurs électroniques hétérogènes sur un même bus de communication, démarche rigoureuse de diagnostic et de correction de dysfonctionnements matériels et logiciels, ainsi que conception d'une chaîne logicielle complète allant du capteur jusqu'à une interface web de suivi (communication série, base de données relationnelle, développement web côté serveur et visualisation de données). Le projet a également permis d'appréhender concrètement l'écart, souvent sous-estimé, entre un modèle d'intelligence artificielle performant en simulation et son comportement une fois confronté aux contraintes réelles d'un système embarqué et de capteurs physiques imparfaits.

\section{Perspectives}
Plusieurs perspectives d'amélioration se dégagent de ce travail. L'enrichissement du jeu de données avec des mesures réelles, et non uniquement synthétiques, permettrait de renforcer la robustesse du modèle en conditions réelles. Le remplacement ou la réécriture de l'algorithme de traitement du signal cardiaque permettrait de dépasser la contrainte actuelle de la fenêtre de capture. Une calibration du capteur de température sur un échantillon plus large de sujets renforcerait la fiabilité de cette mesure. La remontée de données actuellement filaire (liaison série) pourrait évoluer vers une transmission WiFi optionnelle, tout en conservant le principe d'un diagnostic qui ne dépend jamais du réseau. Enfin, le développement d'une application mobile pour le personnel soignant, ainsi qu'une validation clinique par du personnel médical qualifié, constitueraient des étapes naturelles vers un dispositif plus abouti, dans la continuité d'un futur mémoire ou projet de fin de cycle.

% ===================== CHAPITRE 6 : BIBLIOGRAPHIE ET WEBOGRAPHIE =====================
\chapter{Bibliographie et Webographie}

\section*{Bibliographie}
\addcontentsline{toc}{section}{Bibliographie}

\subsection*{Justification du recours à des données synthétiques}
\begin{itemize}
    \item Gonzales, A., Guruswamy, G., Smith, S. R. \textit{Synthetic data in health care: A narrative review}. PLOS Digital Health. 2023;2(1):e0000082. doi: 10.1371/journal.pdig.0000082. Disponible sur : \url{https://pmc.ncbi.nlm.nih.gov/articles/PMC9931305/}, consulté en juillet 2026.
    \item Kokosi, T., Harron, K. \textit{Synthetic data in medical research}. BMJ Medicine. 2022;1(1):e000167. doi: 10.1136/bmjmed-2022-000167. Disponible sur : \url{https://bmjmedicine.bmj.com/content/1/1/e000167}, consulté en juillet 2026.
    \item Organisation mondiale de la santé (OMS). \textit{Principes relatifs aux données de l'OMS}. Disponible sur : \url{https://data.who.int/fr/about/data/who-data-principles}, consulté en juillet 2026.
\end{itemize}

\subsection*{Seuils médicaux de référence (constantes vitales, 19 classes)}
\begin{itemize}
    \item MSD Manuals. \textit{Manuel MSD -- Édition professionnelle, tables de référence cliniques}. Disponible sur : \url{https://www.msdmanuals.com/professional/pages-with-widgets/tables}, consulté en juillet 2026.
    \item Medtronic. \textit{Normal vital signs -- reference infosheet (pulse oximetry, respiratory rate monitoring)}. Disponible sur : \url{https://www.medtronic.com/content/dam/medtronic-wide/public/western-europe/products/patient-monitoring/pulse-oximetry/resparray-monitor-normal-vitals-infosheet.pdf}, consulté en juillet 2026.
    \item American Heart Association. \textit{Pediatric Advanced Life Support (PALS) Guidelines -- Normal Pediatric Vital Signs}. Disponible sur : \url{https://papers.ucalgary.ca/paediatrics/assets/normal-pediatric-vital-signs.pdf}, consulté en juillet 2026.
    \item Organisation mondiale de la santé (OMS). \textit{Reference Card for WHO Emergency Unit}. Disponible sur : \url{https://www.who.int/docs/default-source/documents/emergency-care/reference-card-for-who-emergency-unit-form-general.pdf}, consulté en juillet 2026.
\end{itemize}

\textit{Remarque : les dates de consultation ci-dessus sont indicatives (juillet 2026, période de rédaction du présent document) ; l'étudiant est invité à les ajuster si une consultation ultérieure a lieu, et à compléter cette liste avec toute autre source effectivement utilisée durant le projet (cours, documentation technique des bibliothèques logicielles, etc.).}

% ===================== CHAPITRE 7 : ANNEXES =====================
\chapter{Annexes}

\section{Annexe 1 -- Extrait du code d'inférence embarquée}
\begin{lstlisting}[language=C++]
float applyZScoreScaling(float rawValue, float mean, float stdDev) {
    if (stdDev == 0.0f) return 0.0f;
    return (rawValue - mean) / stdDev;
}

int runLocalInference(const PatientData &patient) {
    input->data.f[0] = applyZScoreScaling(patient.age, MEAN_AGE, STD_AGE);
    input->data.f[1] = applyZScoreScaling(patient.bpm, MEAN_BPM, STD_BPM);
    input->data.f[2] = applyZScoreScaling(patient.spo2, MEAN_SPO2, STD_SPO2);
    input->data.f[3] = applyZScoreScaling(patient.temperature, MEAN_TEMP, STD_TEMP);

    TfLiteStatus invoke_status = interpreter->Invoke();

    int predictedClass = 0;
    float maxConfidence = -1.0;
    for (int i = 0; i < NUM_CLASSES; i++) {
        float confidence = output->data.f[i];
        if (confidence > maxConfidence) {
            maxConfidence = confidence;
            predictedClass = i;
        }
    }
    return predictedClass;
}
\end{lstlisting}

\section{Annexe 2 -- Extrait de la correction de lecture NFC (authentification)}
\begin{lstlisting}[language=C++]
uint8_t keyA[6] = { 0xFF, 0xFF, 0xFF, 0xFF, 0xFF, 0xFF };
if (!nfc.mifareclassic_AuthenticateBlock(uid, uidLength, 4, 0, keyA)) {
    Serial.println("Echec authentification bloc 4 (lecture impossible).");
} else if (nfc.mifareclassic_ReadDataBlock(4, data)) {
    readSuccess = true;
    if (data[0] > 0 && data[0] <= 120) {
        extractedAge = (float)data[0];
    }
}
\end{lstlisting}

\section{Annexe 3 -- Architecture du modèle (Python/Keras)}
\begin{lstlisting}[language=Python]
model = Sequential([
    Dense(32, activation='relu', input_shape=(4,)),
    Dropout(0.1),
    Dense(16, activation='relu'),
    Dense(19, activation='softmax')
])

model.compile(
    optimizer='adam',
    loss='categorical_crossentropy',
    metrics=['accuracy']
)
\end{lstlisting}

\section{Annexe 4 -- Liste des 19 classes diagnostiquées}
\begin{table}[H]
\centering
\small
\begin{tabular}{clcl}
\toprule
Idx & Classe & Idx & Classe \\
\midrule
0 & Adulte Normal & 10 & Fièvre Élevée (Infection) \\
1 & Enfant Normal & 11 & Hypoxie Sévère (Détresse) \\
2 & Senior Normal & 12 & Tachycardie Sévère \\
3 & Variation Physiologique Légère & 13 & Bradycardie Sévère (Syncope) \\
4 & Fébrilicule (Alerte) & 14 & Choc Septique \\
5 & Tachycardie Légère (Stress) & 15 & Hypothermie Sévère \\
6 & Bradycardie Légère & 16 & Détresse Respiratoire Aiguë \\
7 & Hypoxie Légère & 17 & Infection Pédiatrique Grave \\
8 & Dysthémie Thermique (Froid) & 18 & Choc Critique (Instable) \\
9 & Tachycardie Infantile & & \\
\bottomrule
\end{tabular}
\caption{Correspondance entre les indices de sortie du modèle et les 19 classes}
\end{table}

\section{Annexe 5 -- Format du protocole série et exemple de ligne transmise}
\begin{lstlisting}[language=C++, basicstyle=\ttfamily\footnotesize]
// Format imprime par le dispositif a chaque mesure :
// MEDBOX;uid;age;bpm;spo2;temperature;confiance;classe

// Exemple reel :
// MEDBOX;A3F2C19B;8;95.0;98.0;36.38;0.9234;1
\end{lstlisting}

\begin{lstlisting}[language=Python, caption={Boucle d'ecoute simplifiee du pont Python}]
# ouvrir le port serie et la connexion a la base
while True:
    ligne = port_serie.readline().decode().strip()
    if ligne.startswith("MEDBOX;"):
        champs = ligne.split(";")
        uid, age, bpm, spo2, temp, confiance, classe = champs[1:]
        enregistrer_mesure(uid, age, bpm, spo2, temp, confiance, classe)
    # sinon, la ligne est ignoree (message de debogage du dispositif)
\end{lstlisting}

\section{Annexe 6 -- Intégration Chart.js (PHP vers JavaScript)}
\begin{lstlisting}[language=PHP]
// Cote PHP : lecture des mesures depuis la base, puis encodage JSON
$serieBpm = [78, 95, 110];
$jsonBpm = json_encode($serieBpm); // "[78,95,110]"
\end{lstlisting}
\begin{lstlisting}[language=Java, caption={Creation de la courbe cote JavaScript}]
new Chart(document.getElementById('chartBpm'), {
    type: 'line',
    data: {
        labels: labels,
        datasets: [{
            data: dataBpm,
            borderColor: '#2E7D8E',
            fill: true
        }]
    }
});
\end{lstlisting}

\section{Annexe 7 -- Synthèse des choix logiciels retenus}
\begin{table}[H]
\centering
\small
\begin{tabular}{p{5.5cm}p{8.5cm}}
\toprule
\textbf{Choix} & \textbf{Justification} \\
\midrule
Calibration par offset additif simple & Absence de moyens et de temps pour collecter un jeu de données de calibration suffisamment large pour une régression multi-variable. \\
Mesure en plusieurs cycles + médiane & La bibliothèque de calcul du rythme cardiaque impose une taille de buffer fixe non modifiable ; la multiplication des cycles compense cette contrainte. \\
Mode de saisie manuelle des constantes vitales & Permet de valider les dix-neuf classes de sortie du modèle indépendamment de la fiabilité des capteurs physiques. \\
Firmware d'écriture NFC séparé & Évite d'alourdir le firmware embarqué final avec du code de préparation de badges non nécessaire en usage courant. \\
Filtrage par plage physiologique plausible & Empêche qu'une valeur aberrante isolée ne pollue le résultat final, sans nécessiter d'algorithme de traitement du signal plus complexe. \\
Liaison série plutôt que WiFi & Cohérence avec l'objectif d'autonomie hors ligne du dispositif ; absence de configuration réseau ; débogage plus simple. \\
Remontée opportuniste des données & Garantit que le diagnostic ne dépend jamais de la disponibilité de la base de données ou du pont. \\
Chart.js hébergé localement & Permet à la plateforme web de fonctionner sans connexion internet, cohérent avec le reste du système. \\
\bottomrule
\end{tabular}
\caption{Choix logiciels retenus et justifications}
\end{table}

\end{document}

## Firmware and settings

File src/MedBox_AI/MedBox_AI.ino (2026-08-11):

#include <Wire.h>
#include "config.h"
#include "nfc_module.h"
#include "sensors_module.h"
#include "ia_inference.h"
#include "display_module.h"

// ============================================================================
// DEFINITION DES ETATS DE LA MACHINE
// ============================================================================


// Variable d'état courante (On commence par l'attente NFC)
MedBoxState currentState = STATE_WAIT_NFC;

// ============================================================================
// ALLOCATION MEMOIRE UNIQUE (SRAM)
// ============================================================================
// L'ESP32 réserve ici l'espace mémoire pour stocker les structures de données
PatientData currentPatient;

// Variable de contrôle pour le timing de l'affichage du diagnostic
unsigned long displayStartTime = 0;
const unsigned long RESULT_TIMEOUT = 10000; // Affichage du diagnostic pendant 10 secondes

// ============================================================================
// SETUP : INITIALISATION MATÉRIELLE
// ============================================================================
void setup() {
    Serial.begin(115200);
    while (!Serial); // Optionnel : attend l'ouverture du moniteur série
    
    Serial.println("--- DEMARRAGE DE MEDBOX AI ---");

    // 1. Initialisation du bus I2C (Écran, Capteurs, PN532 selon ton câblage)
    Wire.begin();

    // 2. Initialisation de chaque bloc modulaire
    if (!initDisplayModule()) {
        Serial.println("❌ Erreur critique : Ecran OLED non fonctionnel.");
        while(1);
    }
    
    initSensors();          // Initialise MLX90614, MAX30102 et le Buzzer
    initNFC();        // Initialise le lecteur PN532
    
    initTinyML();

    Serial.println("🚀 MedBox AI est totalement operationnel !");
    displaySplashWait(); // Affiche "Veuillez scanner un badge NFC..."
}

// ============================================================================
// LOOP : MACHINE À ÉTATS PRINCIPALE
// ============================================================================
void loop() {
    
    switch (currentState) {
        
        // --------------------------------------------------------------------
        // ÉTAT 1 : ATTENTE DU BADGE NFC (POUR L'ÂGE)
        // --------------------------------------------------------------------
        case STATE_WAIT_NFC: {
            float extractedAge = 0.0;
            String extractedUID = "";
            
            // On vérifie de manière non-bloquante si une carte se présente
            if (checkForNFCBadge(extractedAge, extractedUID)) {
                // Une carte a été lue avec succès ! On stocke l'âge et l'UID dans la RAM
                currentPatient.age = extractedAge;
                currentPatient.uid = extractedUID;
                
                Serial.print("👤 Patient identifie. Age recupere : ");
                Serial.print(currentPatient.age);
                Serial.println(" ans.");
                
                // Confirmation visuelle immédiate à l'écran (sinon l'OLED reste
                // bloqué sur "Veuillez scanner..." jusqu'à la fin de la mesure des capteurs)
                display.clearDisplay();
                display.setTextSize(1);
                display.setCursor(0, 16);
                display.println("[ BADGE RECONNU ]");
                display.setCursor(0, 32);
                display.print("Age : ");
                display.print((int)currentPatient.age);
                display.println(" ans");
                display.setCursor(0, 48);
                display.println("Preparation...");
                display.display();

                // Confirmation sonore : un bip court signale la reconnaissance du badge
                beep(150);

                delay(2000); // Laisse 2 secondes pour lire la confirmation à l'écran

                // Transition : On passe immédiatement à la lecture des capteurs
                currentState = STATE_READ_SENSORS;
            }
            break;
        }

        // --------------------------------------------------------------------
        // ÉTAT 2 : CAPTURE BLOQUANTE DES CONSTANTES VITALES
        // --------------------------------------------------------------------
        case STATE_READ_SENSORS: {
            float temp = 0.0;
            float bpm = 0.0;
            float spo2 = 0.0;

            bool captureSuccess;

            #if MANUAL_INPUT_MODE
                // Mode test : saisie manuelle via le Moniteur Serie (pas de capteurs physiques)
                captureSuccess = readManualSensorInputs(bpm, spo2, temp);
            #else
                // Mode normal : capture bloquante sur la température puis le pouls.
                // Dès que la présence est validée, elle prend 100 points cardiaques.
                captureSuccess = readMedicalSensors(bpm, spo2, temp);
            #endif

            if (captureSuccess) {
                // Si l'algorithme valide la qualité du signal, on enregistre
                currentPatient.temperature = temp;
                currentPatient.bpm = bpm;
                currentPatient.spo2 = spo2;

                // On rafraîchit l'OLED pour afficher un récapitulatif des données brutes
                displayLiveMetrics(currentPatient);
                delay(2000); // Laisse 2 secondes pour lire les constantes à l'écran

                // Transition : Tout est en mémoire, on passe à l'IA
                currentState = STATE_INFERENCE;
            } else {
                // Si la mesure a échoué (doigt qui bouge), la fonction renvoie false.
                // On réinitialise l'écran d'attente des capteurs et on retente la lecture.
                displayLiveMetrics(currentPatient); 
            }
            break;
        }

        // --------------------------------------------------------------------
        // ÉTAT 3 : APPLICATION DU SCALING ET INFERENCE DE L'IA
        // --------------------------------------------------------------------
        case STATE_INFERENCE: {
            Serial.println("🧠 Lancement de l'inference TinyML locale...");
            
            // Exécute le Z-Score et invoque l'interpréteur TensorFlow Lite Micro
            float confiance = 0.0;
            int predictedClass = runLocalInference(currentPatient, confiance);
            
            if (predictedClass >= 0) {
                // On memorise la confiance dans la structure patient
                currentPatient.confiance = confiance;

                // ----------------------------------------------------------------
                // TRANSMISSION SERIE VERS LE PONT PYTHON (remontee vers la base)
                // Format : MEDBOX;uid;age;bpm;spo2;temperature;confiance;classe
                // ----------------------------------------------------------------
                Serial.print("MEDBOX;");
                Serial.print(currentPatient.uid);            Serial.print(";");
                Serial.print(currentPatient.age, 0);         Serial.print(";");
                Serial.print(currentPatient.bpm, 1);         Serial.print(";");
                Serial.print(currentPatient.spo2, 1);        Serial.print(";");
                Serial.print(currentPatient.temperature, 2); Serial.print(";");
                Serial.print(currentPatient.confiance, 4);   Serial.print(";");
                Serial.println(predictedClass);

                // Envoi de l'index prédit à l'écran OLED
                displayDiagnosticResult(predictedClass);
                
                // Enregistrement du moment de l'affichage pour gérer le timeout
                displayStartTime = millis();
                
                // Transition : On bascule sur l'affichage fixe du diagnostic
                currentState = STATE_SHOW_RESULT;
            } else {
                // Sécurité en cas d'erreur de calcul de l'interpréteur
                Serial.println("❌ Échec de l'analyse. Retour à la case départ.");
                displaySplashWait();
                currentState = STATE_WAIT_NFC;
            }
            break;
        }

        // --------------------------------------------------------------------
        // ÉTAT 4 : AFFICHAGE DU RÉSULTAT ET FIN DE SESSION
        // --------------------------------------------------------------------
        case STATE_SHOW_RESULT: {
            // L'écran affiche le diagnostic. On attend passivement pendant 10 secondes
            // pour laisser le temps de lire le verdict de l'OMS.
            if (millis() - displayStartTime >= RESULT_TIMEOUT) {
                Serial.println("🔄 Session terminee. Reset des donnees et attente nouveau patient.");
                
                // Remise à zéro de la structure pour le prochain patient
                currentPatient = PatientData(); 
                
                // Retour à l'écran d'accueil
                displaySplashWait();
                currentState = STATE_WAIT_NFC;
            }
            break;
        }
    }
}

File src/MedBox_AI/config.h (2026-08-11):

#ifndef CONFIG_H
#define CONFIG_H

#include <Arduino.h>

// ============================================================================
// 1. DÉFINITION DES ÉTATS DE LA MACHINE (STATE MACHINE)
// ============================================================================
enum MedBoxState {
    STATE_INIT,          // Initialisation des périphériques (OLED, NFC, Capteurs) et de TF Lite
    STATE_WAIT_NFC,      // Attente active du scan du badge patient (extraction de l'âge)
    STATE_READ_SENSORS,  // Capture et stabilisation des données (MAX30102 et MLX90614)
    STATE_SCALING,       // Normalisation mathématique des données par Z-Score
    STATE_INFERENCE, 
    STATE_SHOW_RESULT    // Calcul TinyML local et affichage du diagnostic précis
};

// ============================================================================
// 2. STRUCTURE DE DONNÉES DU PATIENT
// ============================================================================
struct PatientData {
    // Identité (UID du badge NFC, en hexadecimal) - sert d'identifiant patient
    String uid = "";

    // Données brutes (Raw Data collectées)
    float age = 0.0;
    float bpm = 0.0;
    float spo2 = 0.0;
    float temperature = 0.0;

    // Confiance du modele sur la classe predite (0.0 a 1.0)
    float confiance = 0.0;

    // Données normalisées prêtes pour le modèle TinyML (Inputs)
    float age_scaled = 0.0;
    float bpm_scaled = 0.0;
    float spo2_scaled = 0.0;
    float temperature_scaled = 0.0;
};

// ============================================================================
// 3. CONSTANTES DE NORMALISATION Z-SCORE (scaler_medbox.pkl)
// ============================================================================
// Formule mathématique appliquée : (Valeur - Moyenne) / Écart-type
// L'ordre des features respecte strictement le dataset : [Age, BPM, SpO2, Temperature]

const float MEAN_AGE = 40.76118421;
const float STD_AGE  = 24.57877655;

const float MEAN_BPM = 100.52855263;
const float STD_BPM  = 35.53269770;

const float MEAN_SPO2 = 93.34250000;
const float STD_SPO2  = 6.04989639;

const float MEAN_TEMP = 37.05082895;
const float STD_TEMP  = 1.83151845;

// ============================================================================
// 4. PARAMÈTRES TENSORFLOW LITE MICRO
// ============================================================================
const int TENSOR_ARENA_SIZE = 8 * 1024; // 8 Ko alloués en SRAM pour les calculs de l'IA
const int NUM_CLASSES = 19;             // Les 19 pathologies/états du dataset (0 à 18 en C++)

// ============================================================================
// 5. LISTE DES PATHOLOGIES ET ÉTATS NORMAUX (INDEXÉS DE 0 À 18)
// ============================================================================
// Tableau de correspondance pour traduire l'index de sortie de l'IA en texte clair.
// Correspond exactement aux 19 classes (1 à 19) de ton fichier Excel.
// Les accents ont été retirés pour éviter les bugs d'affichage sur l'écran OLED.

const char* const PATHOLOGY_NAMES[NUM_CLASSES] = {
    "Adulte Normal",                  // Index 0 -> Classe 1
    "Enfant Normal",                  // Index 1 -> Classe 2
    "Senior Normal",                  // Index 2 -> Classe 3
    "Var. Physiologique Legere",      // Index 3 -> Classe 4
    "Febrilicule (Alerte)",           // Index 4 -> Classe 5
    "Tachycardie Legere (Stress)",    // Index 5 -> Classe 6
    "Bradycardie Legere",             // Index 6 -> Classe 7
    "Hypoxie Legere",                 // Index 7 -> Classe 8
    "Dysthemie Thermique (Froid)",    // Index 8 -> Classe 9
    "Tachycardie Infantile",          // Index 9 -> Classe 10
    "Fievre Elevee (Infection)",      // Index 10 -> Classe 11
    "Hypoxie Severe (Detresse)",      // Index 11 -> Classe 12
    "Tachycardie Severe",             // Index 12 -> Classe 13
    "Bradycardie Severe (Syncope)",   // Index 13 -> Classe 14
    "Choc Septique",                  // Index 14 -> Classe 15
    "Hypothermie Severe",             // Index 15 -> Classe 16
    "Detresse Respi. Aigue",          // Index 16 -> Classe 17
    "Infection Pediatrique Grave",    // Index 17 -> Classe 18
    "Choc Critique (Instable)"        // Index 18 -> Classe 19
};
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

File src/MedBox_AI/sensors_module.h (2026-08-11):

#ifndef SENSORS_MODULE_H
#define SENSORS_MODULE_H

#include <Wire.h>
#include <MAX30105.h>           // Bibliothèque SparkFun pour le MAX30102
#include "spo2_algorithm.h"     // Algorithme d'extraction officiel de Maxim Integrated
#include <Adafruit_MLX90614.h>   // Bibliothèque Adafruit pour le MLX90614
#include <Adafruit_SSD1306.h>   // Pour mettre à jour l'OLED pendant les étapes
#include "config.h"

// Si BUZZER_PIN n'est pas encore mis dans config.h, on le définit ici par sécurité
#ifndef BUZZER_PIN
#define BUZZER_PIN 13
#endif

// Accès à l'instance globale de l'écran OLED définie dans display_module.h
extern Adafruit_SSD1306 display;

// Création des instances pour chaque capteur
MAX30105 maxSensor;
Adafruit_MLX90614 mlxSensor = Adafruit_MLX90614();

// Tampons de stockage requis pour l'algorithme.
// !! BUFFER_SIZE DOIT rester à 100 !! La fonction maxim_heart_rate_and_oxygen_saturation()
// utilise des tableaux internes de taille FIXE (100), codés en dur dans spo2_algorithm.h.
// Envoyer plus de 100 échantillons fait écrire la fonction hors de ces tableaux internes,
// ce qui corrompt la mémoire et provoque un crash (Guru Meditation / LoadProhibited).
// Pour compenser une fenêtre courte, on multiplie les CYCLES de 100 échantillons (voir
// NUM_MEASURE_CYCLES plus bas) plutôt que d'agrandir un seul cycle.
#define BUFFER_SIZE 100
uint32_t irBuffer[BUFFER_SIZE];  
uint32_t redBuffer[BUFFER_SIZE]; 

// Variables de sortie pour l'algorithme de Maxim
int8_t spo2Valid;   
int8_t bpmValid;    
int32_t n_spo2;      
int32_t n_heart_rate;

// Bornes physiologiques plausibles pour filtrer les mesures aberrantes
// (l'algorithme Maxim peut marquer "valide" un résultat malgré un signal bruité)
const float BPM_MIN_PLAUSIBLE  = 40.0;
const float BPM_MAX_PLAUSIBLE  = 200.0;
const float SPO2_MIN_PLAUSIBLE = 70.0;
const float SPO2_MAX_PLAUSIBLE = 100.0;

// Nombre de cycles de mesure successifs pour dégager une valeur médiane robuste
// (compense la contrainte des 100 échantillons/cycle imposée par la librairie Maxim)
const int NUM_MEASURE_CYCLES = 5;

// ============================================================================
// FONCTION UTILITAIRE POUR FAIRE BIP
// ============================================================================
void beep(int durationMs) {
    digitalWrite(BUZZER_PIN, HIGH); // Allume le buzzer
    delay(durationMs);              // Attend la durée demandée
    digitalWrite(BUZZER_PIN, LOW);  // Éteint le buzzer
}

// ============================================================================
// INITIALISATION DES CAPTEURS ET DU BUZZER
// ============================================================================
void initSensors() {
    // Configuration de la broche du buzzer en sortie
    pinMode(BUZZER_PIN, OUTPUT);
    digitalWrite(BUZZER_PIN, LOW); // Assure que le buzzer est éteint au départ

    if (!mlxSensor.begin()) {
        Serial.println("❌ MLX90614 non trouve !");
        while (1);
    }

    if (!maxSensor.begin(Wire, I2C_SPEED_FAST)) { 
        Serial.println("❌ MAX30102 non trouve !");
        while (1);
    }

    // Configuration standard du MAX30102
    byte ledBrightness = 60;  // Remis à 60 : la valeur 100 saturait le capteur (DC trop
                               // fort), ce qui écrasait le signal pulsatile (AC) et
                               // provoquait un échec total de détection (-999).
    byte sampleAverage = 4;   // Lisse le signal brut au niveau matériel
    byte ledMode = 2;         
    int sampleRate = 100;     
    int pulseWidth = 411;     
    int adcRange = 4096;      

    maxSensor.setup(ledBrightness, sampleAverage, ledMode, sampleRate, pulseWidth, adcRange);
    Serial.println("✅ Capteurs et Buzzer initialises !");
}

// ============================================================================
// LECTURE DES DONNÉES AVEC RETOUR SONORE ET TRANSITION
// ============================================================================
bool readMedicalSensors(float &calculatedBPM, float &calculatedSpO2, float &calculatedTemp) {
    
    // ---- Etape 1 : Attente active d'une présence humaine (MLX90614) ----
    Serial.println("⏳ En attente d'un patient devant le capteur de temperature...");

    // Instruction affichée à l'écran pendant l'attente de détection de température
    display.clearDisplay();
    display.setTextSize(1);
    display.setCursor(0, 8);
    display.println("[ MESURE TEMP. ]");
    display.drawFastHLine(0, 18, 128, SSD1306_WHITE);
    display.setCursor(0, 28);
    display.println("Approchez le dos");
    display.setCursor(0, 40);
    display.println("de la main du");
    display.setCursor(0, 52);
    display.println("capteur...");
    display.display();
    
    float tempCheck = mlxSensor.readObjectTempC();
    
    // CORRECTION : On met à jour la même variable "tempCheck" sans redéclarer "float"
    while (tempCheck < 32.0) {
        delay(200);
        tempCheck = mlxSensor.readObjectTempC();
    }
    
    // La détection de présence se fait sur la valeur BRUTE (32°C = peau détectée).
    // La valeur STOCKÉE et envoyée à l'IA est corrigée via l'offset de calibration,
    // sinon l'IA reçoit toujours ~32°C et classe systématiquement en hypothermie sévère.
    calculatedTemp = tempCheck + TEMP_OFFSET_CALIBRATION;
    Serial.print("🌡️ Patient detecte ! Temperature : "); 
    Serial.print(calculatedTemp); Serial.println(" C");
    
    // 🔔 PREMIER BIP : Température acquise avec succès
    beep(150);

    // 🕒 --- ÉTAPE DE TRANSITION DE 3 SECONDES ---
    Serial.println("🕒 Pause de transition... Préparez-vous à poser le doigt.");
    
    // Mise à jour de l'OLED pour informer le patient
    display.clearDisplay();
    display.setTextSize(1);
    
    display.setCursor(0, 0);
    display.println("[ MESURE TEMP. OK ]");
    
    display.setCursor(0, 16);
    display.print("Temp : "); display.print(calculatedTemp, 1); display.println(" C");
    
    display.drawFastHLine(0, 28, 128, SSD1306_WHITE);
    
    display.setCursor(0, 36);
    display.println("Preparez votre doigt");
    display.setCursor(0, 48);
    display.println("sur le capteur...");
    display.display();

    // Attente de 3 secondes
    delay(3000); 

    // ---- Etape 2 : Attente que le doigt soit posé ----
    Serial.println("📥 Placez et maintenez le doigt. Capture des donnees en cours...");
    
    display.clearDisplay();
    display.setCursor(0, 16);
    display.println(" Posez votre doigt ");
    display.setCursor(0, 32);
    display.println("  sur le capteur  ");
    display.display();

    // Attente active que le doigt soit posé (détection par le rayon infrarouge)
    while (maxSensor.getIR() < 50000) {
        delay(100);
    }
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

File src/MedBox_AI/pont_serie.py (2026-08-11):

#!/usr/bin/env python3
# -*- coding: utf-8 -*-
# ============================================================================
# pont_serie.py — Pont série entre l'ESP32 (MedBox AI) et la base MySQL
#
# Écoute le port série, intercepte les lignes commençant par "MEDBOX;",
# applique la logique d'enrôlement (badge connu / inconnu) et insère la mesure.
# Les autres lignes (logs du boîtier) sont ignorées.
#
# Format attendu :  MEDBOX;uid;age;bpm;spo2;temperature;confiance;classe
#
# Lancement :  python3 pont_serie.py
# Arrêt     :  Ctrl+C
# ============================================================================

import sys
import time
import serial          # fourni par python3-serial
import pymysql         # fourni par python3-pymysql

# ----------------------------------------------------------------------------
# 1. CONFIGURATION — à ajuster selon ton installation
# ----------------------------------------------------------------------------
SERIAL_PORT = "/dev/ttyUSB0"   # Port de l'ESP32 (voir : ls /dev/ttyUSB* /dev/ttyACM*)
BAUD_RATE   = 115200           # Doit correspondre au Serial.begin() du boîtier

DB_CONFIG = {
    "host":        "localhost",
    "user":        "root",
    "password":    "",
    "database":    "medbox",
    "unix_socket": "/opt/lampp/var/mysql/mysql.sock",  # socket MySQL de XAMPP
    "charset":     "utf8mb4",
}

PREFIXE = "MEDBOX;"            # Seules les lignes commençant par ceci sont traitées
NB_CHAMPS = 8                 # MEDBOX + 7 valeurs -> 8 morceaux après découpage

# ----------------------------------------------------------------------------
# 2. CONNEXION À LA BASE
# ----------------------------------------------------------------------------
def connecter_base():
    """Ouvre une connexion MySQL. Réessaie jusqu'à réussite."""
    while True:
        try:
            conn = pymysql.connect(**DB_CONFIG, autocommit=False)
            print("[Base] Connexion MySQL établie.")
            return conn
        except pymysql.MySQLError as e:
            print(f"[Base] Connexion impossible ({e}). Nouvel essai dans 3 s...")
            time.sleep(3)

# ----------------------------------------------------------------------------
# 3. TRAITEMENT D'UNE LIGNE MEDBOX
# ----------------------------------------------------------------------------
def traiter_mesure(conn, ligne):
    """
    Découpe une ligne MEDBOX, applique la logique d'enrôlement et insère la mesure.
    Renvoie un message de compte-rendu (str) à afficher dans le terminal.
    """
    # Découpage : MEDBOX;uid;age;bpm;spo2;temp;confiance;classe
    morceaux = ligne.split(";")

    if len(morceaux) != NB_CHAMPS:
        return f"IGNORÉE (format inattendu, {len(morceaux)} champs) : {ligne}"

    # morceaux[0] == "MEDBOX", on extrait le reste
    try:
        uid         = morceaux[1].strip()
        age         = int(float(morceaux[2]))
        bpm         = float(morceaux[3])
        spo2        = float(morceaux[4])
        temperature = float(morceaux[5])
        confiance   = float(morceaux[6])
        classe      = int(morceaux[7])
    except ValueError as e:
        return f"IGNORÉE (valeur illisible : {e}) : {ligne}"

    # Contrôles minimaux de cohérence
    if uid == "":
        return f"IGNORÉE (uid vide) : {ligne}"
    if classe < 0 or classe > 18:
        return f"IGNORÉE (classe hors bornes : {classe}) : {ligne}"

    try:
        with conn.cursor() as cur:
            # --- Le badge existe-t-il déjà ? ---
            cur.execute(
                "SELECT id_patient FROM patient WHERE uid_nfc = %s", (uid,)
            )
            row = cur.fetchone()

            if row:
                # Badge CONNU : on réutilise le patient existant
                id_patient = row[0]
                etat = "connu"
            else:
                # Badge INCONNU : création d'un patient en attente de finalisation
                cur.execute(
                    "INSERT INTO patient (uid_nfc, nom, age, statut) "
                    "VALUES (%s, NULL, %s, 'EN_ATTENTE')",
                    (uid, age)
                )
                id_patient = cur.lastrowid
                etat = "nouveau"

            # --- Insertion de la mesure (confiance stockée, temp_brute/cycles laissés NULL) ---
            cur.execute(
                "INSERT INTO mesure "
                "(bpm, spo2, temperature, confiance, id_patient, id_pathologie) "
                "VALUES (%s, %s, %s, %s, %s, %s)",
                (bpm, spo2, temperature, confiance, id_patient, classe)
            )

        conn.commit()
        return (f"ENREGISTRÉE  patient {etat} (id={id_patient}, uid={uid}) "
                f"| BPM={bpm:.0f} SpO2={spo2:.0f}% Temp={temperature:.1f}°C "
                f"| classe={classe} conf={confiance*100:.1f}%")

    except pymysql.MySQLError as e:
        conn.rollback()
        return f"ERREUR base (mesure non enregistrée) : {e}"

# ----------------------------------------------------------------------------
# 4. BOUCLE PRINCIPALE
# ----------------------------------------------------------------------------
def main():
    print("=" * 60)
    print("  Pont série MedBox AI  —  ESP32  ->  MySQL")
    print("=" * 60)

    # Connexion à la base d'abord
    conn = connecter_base()

    # Ouverture du port série
    try:
        ser = serial.Serial(SERIAL_PORT, BAUD_RATE, timeout=1)
    except serial.SerialException as e:
        print(f"[Série] Impossible d'ouvrir {SERIAL_PORT} : {e}")
        print("        Vérifie le port (ls /dev/ttyUSB* /dev/ttyACM*) et les "
              "permissions (groupe dialout).")
        conn.close()
        sys.exit(1)

    print(f"[Série] En écoute sur {SERIAL_PORT} à {BAUD_RATE} bauds.")
    print("        (Ctrl+C pour arrêter)\n")

    try:
        while True:
            # Lecture d'une ligne (jusqu'au retour à la ligne)
            brute = ser.readline()
            if not brute:
                continue  # timeout : rien reçu, on reboucle

            # Décodage tolérant (on ignore les octets non-UTF8 éventuels)
            ligne = brute.decode("utf-8", errors="ignore").strip()
            if not ligne:
                continue

            # Seules les lignes commençant par le préfixe nous intéressent
            if ligne.startswith(PREFIXE):
                horodatage = time.strftime("%H:%M:%S")
                compte_rendu = traiter_mesure(conn, ligne)
                print(f"[{horodatage}] {compte_rendu}")
            # else: ligne de log ordinaire du boîtier -> ignorée silencieusement

    except KeyboardInterrupt:
        print("\n[Arrêt] Interruption demandée. Fermeture propre...")
    finally:
        ser.close()
        conn.close()
        print("[Arrêt] Port série et base fermés. À bientôt.")

if __name__ == "__main__":
    main()

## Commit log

2026-07-12 organisation des fichiers et insertions des fichiers déjàpret
    [dataset_multiclasse_19_pathologies.xlsx]
2026-07-15 ajout de la monographie destiné à la defense academique du projet
    [schema_electronique_MedBoxAI.fzz]
2026-08-11 Modification et ajout de la partie sur la communication serie
2026-08-11 Modification de la monographie
